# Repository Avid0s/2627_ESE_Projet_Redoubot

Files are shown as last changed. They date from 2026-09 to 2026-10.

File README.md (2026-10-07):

# 2627_ESE_PROJET_REDOUBOT

[Diagramme draw.io](https://app.diagrams.net/#G1vOe_3MKJzJUBpPdtP-GZ-P4Yg8ShrS2W#%7B%22pageId%22%3A%22ODYEVYFFD_o6EEWGu_Kz%22%7D)

[PDF MPU 6050](https://docs.google.com/document/d/1O3AgjvM2_tZX7ABNkbS3lNtyRqeFLNvJ6qVK9URJxNs/edit?usp=drive_link)

| Composant | Référence | Lien | Quantité |
|---|---|---|---|
| STM32 | CPU_DS_stm32g431rb | [Datasheet](https://github.com/Avid0s/2627_ESE_Projet_Redoubot/blob/main/Datasheet/CPU_DS_stm32g431rb.pdf) | x1 |
| Drivers moteur | DRV8833 | [Datasheet](https://github.com/Avid0s/2627_ESE_Projet_Redoubot/blob/main/Datasheet/Drivers_drv8833.pdf) | x1 |
| Moteurs | FIT0483 | [Datasheet](https://github.com/Avid0s/2627_ESE_Projet_Redoubot/blob/main/Datasheet/Datasheet_moteur_FIT0483.pdf) | x2|
| Gyroscope/accelerometre | MPU6050 | [Datasheet](https://github.com/Avid0s/2627_ESE_Projet_Redoubot/blob/main/Datasheet/Gyro_MPU-6000_DATASHEET.pdf) | x1 |
| Servomotor | SER0039 | [Datasheet](https://github.com/Avid0s/2627_ESE_Projet_Redoubot/blob/main/Datasheet/Servo_SER0039.pdf) | x2 |
| TOF sensor | VL53LL0X | [Datasheet](https://github.com/Avid0s/2627_ESE_Projet_Redoubot/blob/main/Datasheet/TOF_vl53l0x.pdf) [Breakout Board](https://github.com/lfiack/ENSEA_VL53L0CXV0DH-1)| x1 |
| Capteur de couleur | Adafruit APDS9960 | [Datasheet](https://github.com/Avid0s/2627_ESE_Projet_Redoubot/blob/main/Datasheet/Capteur_Couleur_9075d4adc221e10b04bda232a5ca3905.pdf) | x1 |
| BMS | BQ25896RTWR | [Datasheet](https://github.com/Avid0s/2627_ESE_Projet_Redoubot/blob/main/Datasheet/BMS_bq25896.pdf) | x1 |  
| Batterie Lithium | XX | Fournie par ENSEA | x1 |
| Fuel Gauge | BQ27220YZFR | [Datasheet](https://www.ti.com/lit/ds/symlink/bq27220.pdf?ts=1790240333206&ref_url=https%253A%252F%252Fwww.mouser.fr%252F) | x1 |
| Sonde de programation | Conn_ST_STDC14 | Fournie par ENSEA| x1 |

La facon dont l'implémentation de fonctionnalités sera faite sera la suivante:

1 branche = 1 fonctionnalitée

Les branches seront nommées JMA/nom_de_la_fonctionnalitée pour une branche fonctionnalité de J. Mansard par exemple

Aucun push ne sera fait directement sur le main, tout sera merge post peer review

Cette methodologie vise à éviter les merge conflicts et simplifier l'assemblage des différents modules

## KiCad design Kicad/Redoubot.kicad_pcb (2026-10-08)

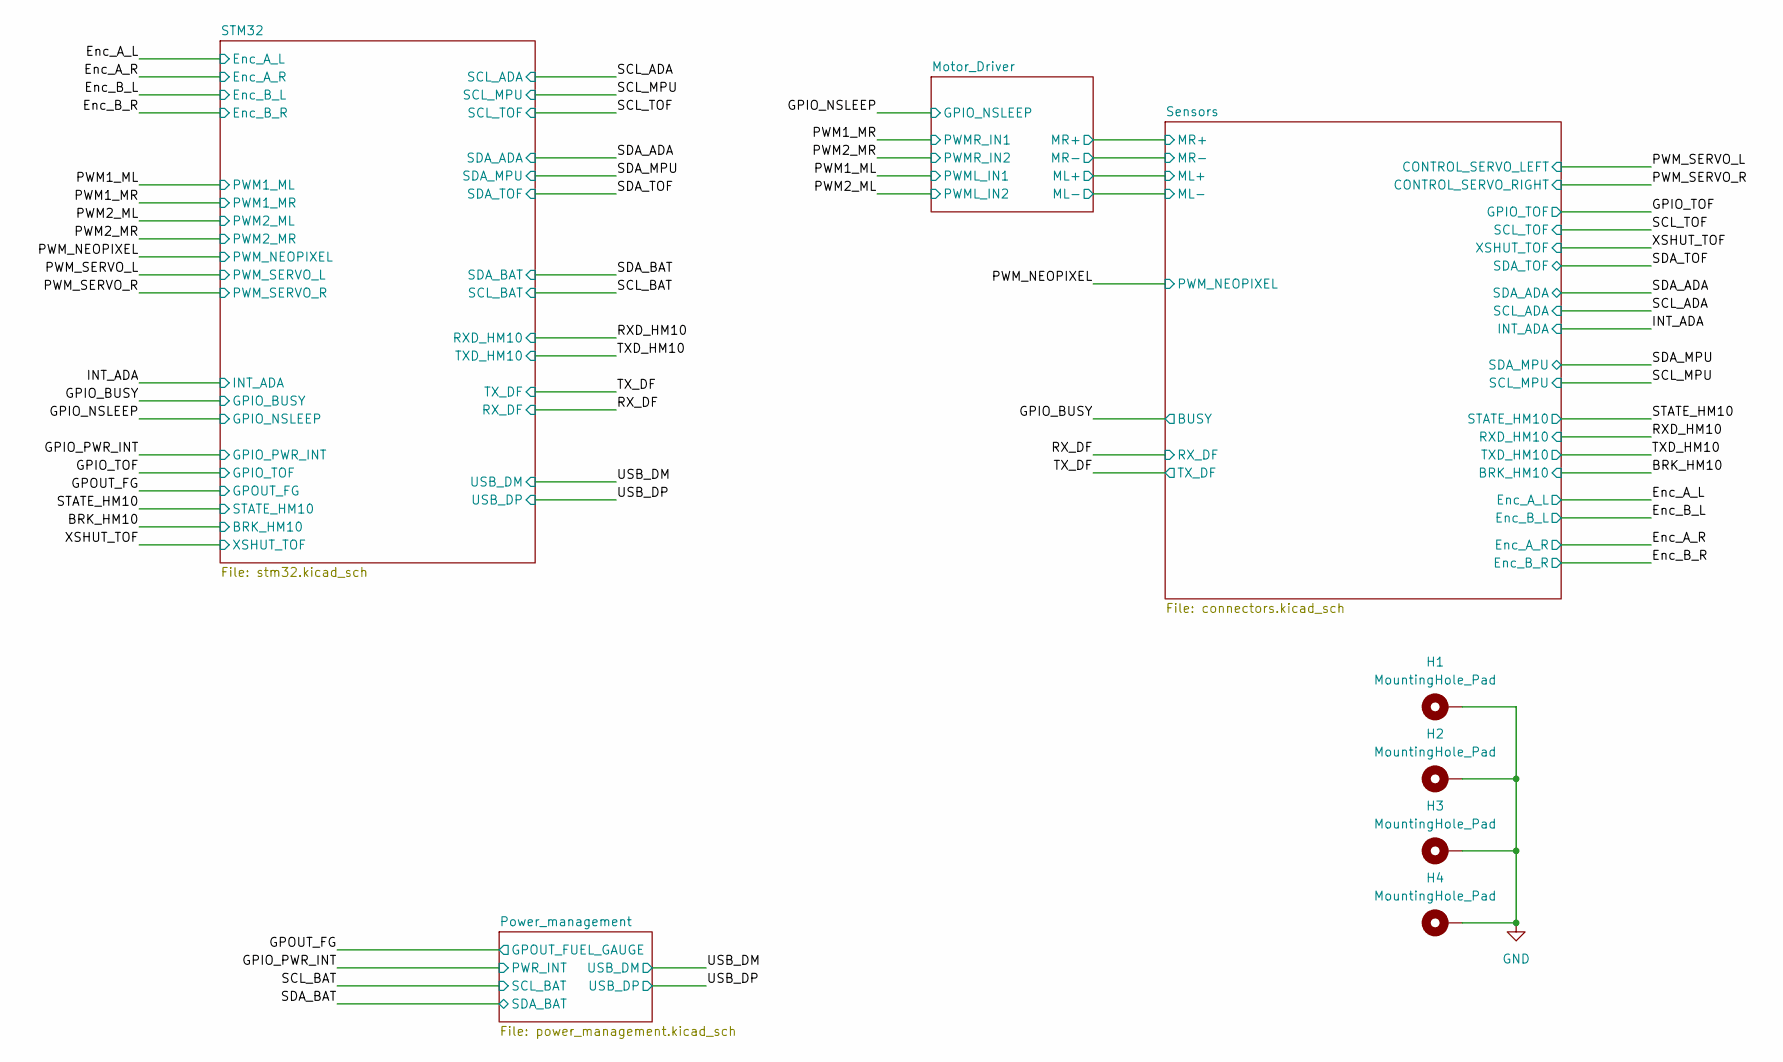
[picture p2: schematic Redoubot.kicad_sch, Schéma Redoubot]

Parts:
H1, H2, H3, H4: MountingHole_Pad; MountingHole_3.2mm_M3_ISO7380_Pad_TopBottom

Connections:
GND: H1.1 (1_1), H2.1 (1_1), H3.1 (1_1), H4.1 (1_1); also elsewhere on the board

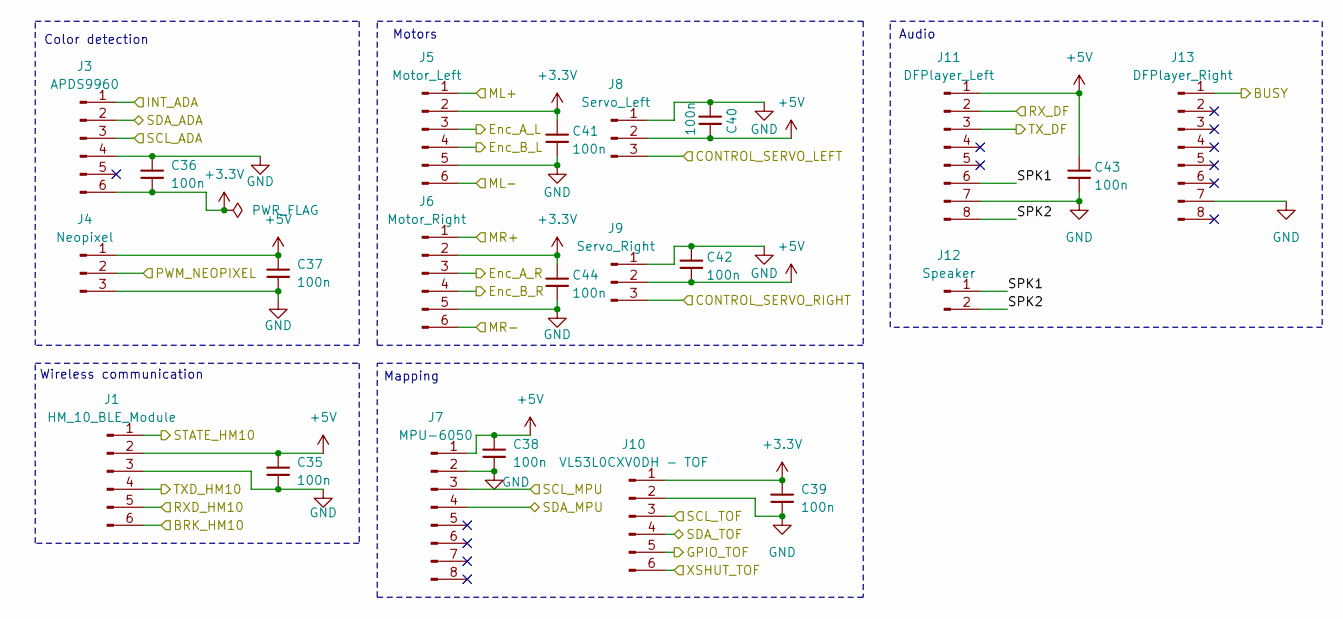
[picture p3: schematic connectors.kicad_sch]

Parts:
C35, C36, C37, C38, C39, C40, C41, C42, C43, C44: 100n; C_0402_1005Metric; JLCPCB Part # C1525
J1: HM_10_BLE_Module; JST_XH_B6B-XH-A_1x06_P2.50mm_Vertical
J3: APDS9960; JST_XH_B6B-XH-A_1x06_P2.50mm_Vertical
J4: Neopixel; JST_XH_B3B-XH-A_1x03_P2.50mm_Vertical
J5: Motor_Left; JST_XH_B6B-XH-A_1x06_P2.50mm_Vertical
J6: Motor_Right; JST_XH_B6B-XH-A_1x06_P2.50mm_Vertical
J7: MPU-6050; PinSocket_1x08_P2.54mm_Vertical; LCSC C24112
J8: Servo_Left; JST_XH_B3B-XH-A_1x03_P2.50mm_Vertical
J9: Servo_Right; JST_XH_B3B-XH-A_1x03_P2.50mm_Vertical
J10: VL53L0CXV0DH - TOF; JST_XH_B6B-XH-A_1x06_P2.50mm_Vertical; LCSC C91199
J11: DFPlayer_Left; PinSocket_1x08_P2.54mm_Vertical
J12: Speaker; JST_XH_B2B-XH-A_1x02_P2.50mm_Vertical
J13: DFPlayer_Right; PinSocket_1x08_P2.54mm_Vertical

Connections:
+3.3V: C36.2, C39.1, C41.1, C44.1, J3.6, J5.2, J6.2, J10.1; also elsewhere on the board
+5V: C35.1, C37.1, C38.1, C40.2, C42.2, C43.1, J1.2, J4.1, J7.1, J8.2, J9.2, J11.1; also elsewhere on the board
/BRK_HM10: J1.6; also elsewhere on the board
/Enc_A_L: J5.3; also elsewhere on the board
/Enc_A_R: J6.3; also elsewhere on the board
/Enc_B_L: J5.4; also elsewhere on the board
/Enc_B_R: J6.4; also elsewhere on the board
/GPIO_BUSY: J13.1; also elsewhere on the board
/GPIO_TOF: J10.5; also elsewhere on the board
/INT_ADA: J3.1; also elsewhere on the board
/Motor_Driver/ML+: J5.1; also elsewhere on the board
/Motor_Driver/ML-: J5.6; also elsewhere on the board
/Motor_Driver/MR+: J6.1; also elsewhere on the board
/Motor_Driver/MR-: J6.6; also elsewhere on the board
/PWM_NEOPIXEL: J4.2; also elsewhere on the board
/PWM_SERVO_L: J8.3; also elsewhere on the board
/PWM_SERVO_R: J9.3; also elsewhere on the board
/RXD_HM10: J1.5; also elsewhere on the board
/RX_DF: J11.2; also elsewhere on the board
/SCL_ADA: J3.3, J7.3, J10.3; also elsewhere on the board
/SDA_ADA: J3.2, J7.4, J10.4; also elsewhere on the board
/STATE_HM10: J1.1; also elsewhere on the board
/Sensors/SPK1: J11.6, J12.1
/Sensors/SPK2: J11.8, J12.2
/TXD_HM10: J1.4; also elsewhere on the board
/TX_DF: J11.3; also elsewhere on the board
/XSHUT_TOF: J10.6; also elsewhere on the board
GND: C35.2, C36.1, C37.2, C38.2, C39.2, C40.1, C41.2, C42.1, C43.2, C44.2, J1.3, J3.4, J4.3, J5.5, J6.5, J7.2, J8.1, J9.1, J10.2, J11.7, J13.7; also elsewhere on the board

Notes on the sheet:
Motors
Wireless communication
Color detection
Mapping
Audio

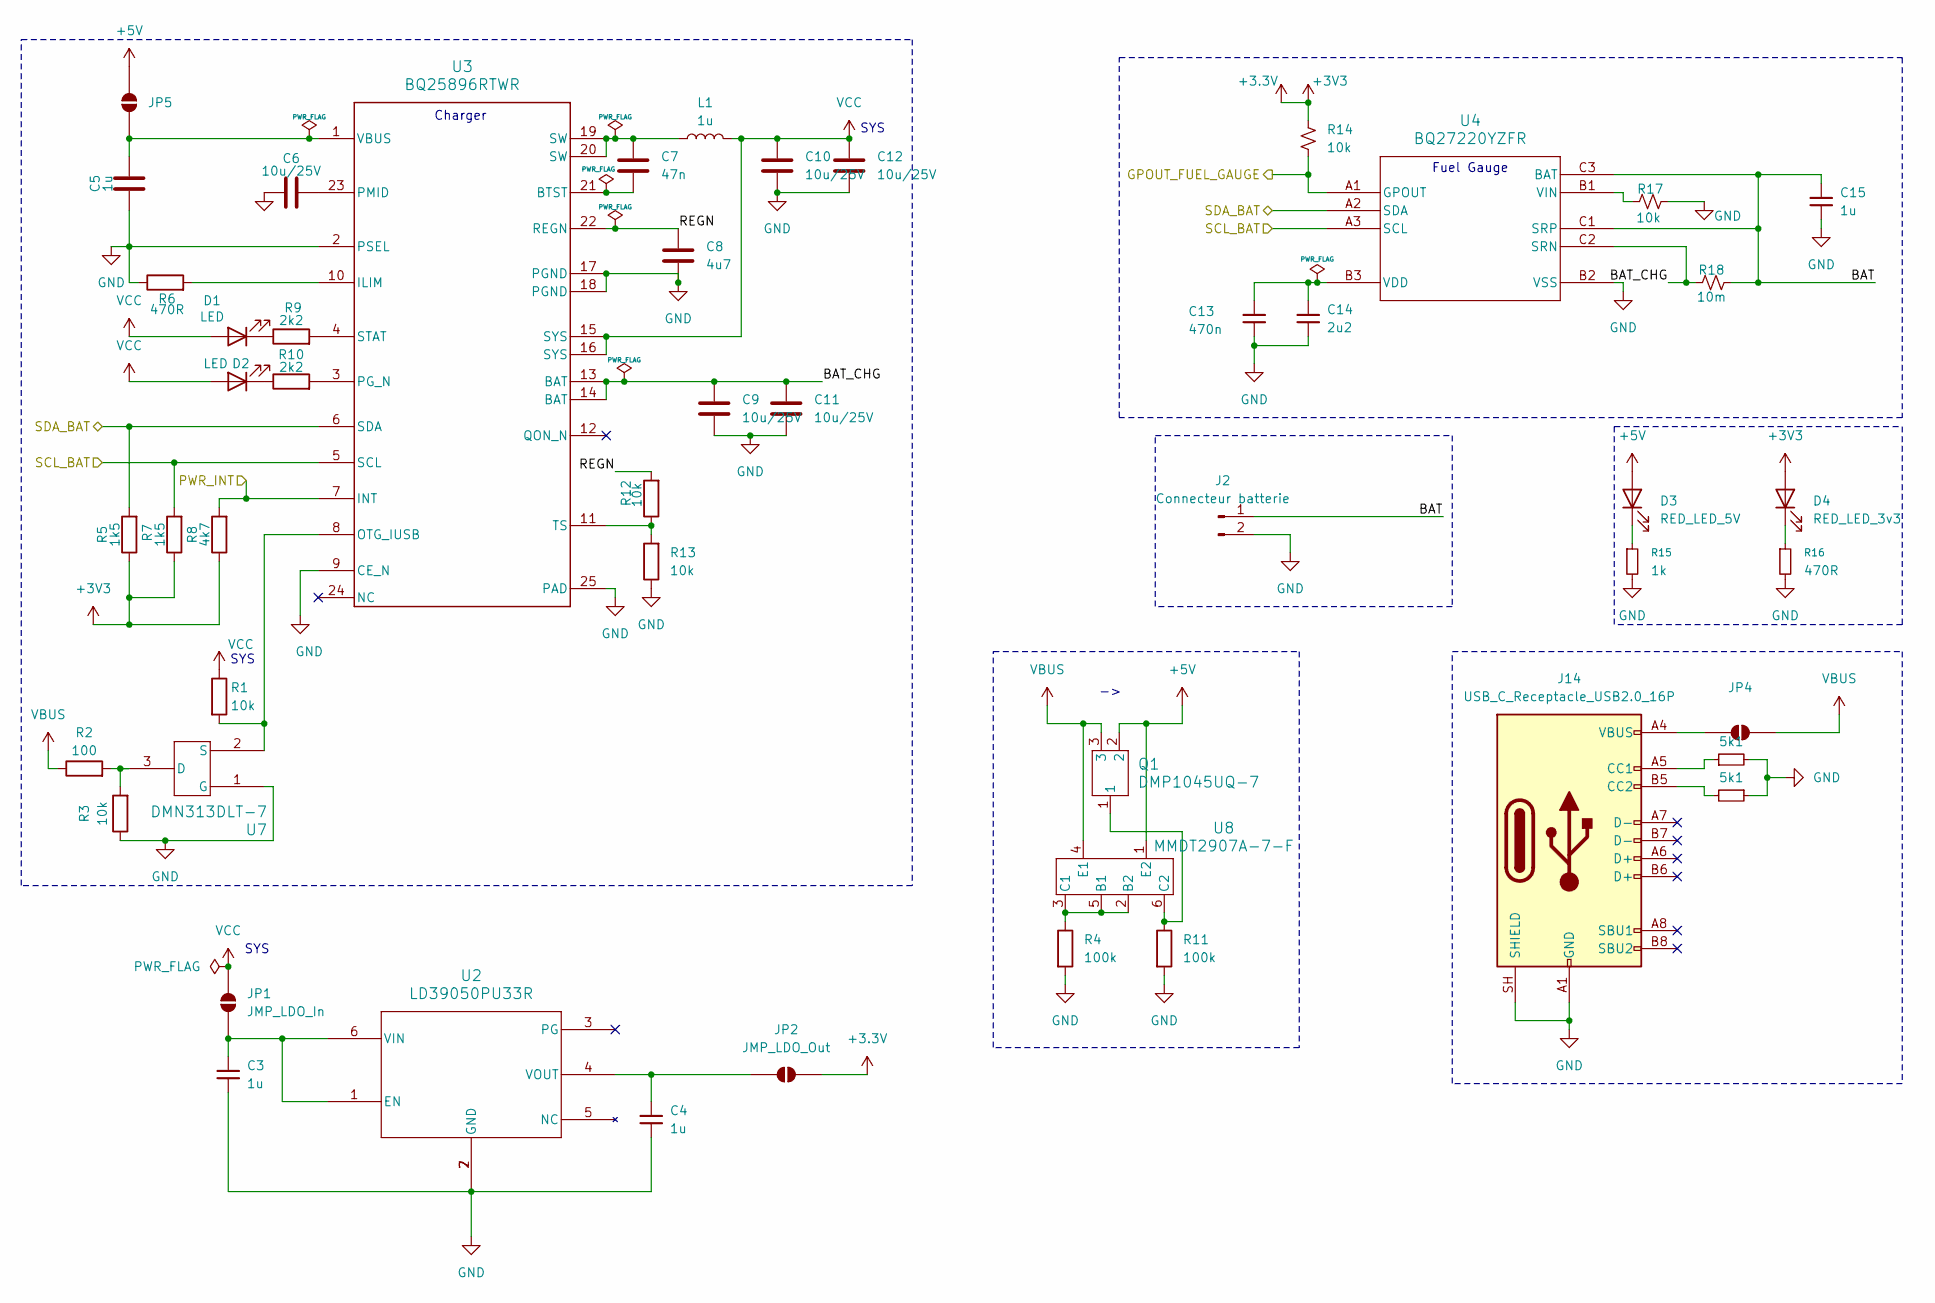
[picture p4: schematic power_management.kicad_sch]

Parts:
C3, C4, C5, C15: 1u; C_0402_1005Metric; JLCPCB Part # C52923
C6, C9, C10, C11, C12: 10u/25V; C_0603_1608Metric; JLCPCB Part # C96446
C7: 47n; C_0603_1608Metric; JLCPCB Part # C1622
C8: 4u7; C_0402_1005Metric; JLCPCB Part # C23733
C13: 470n; C_0603_1608Metric; JLCPCB Part # C1623
C14: 2u2; C_0402_1005Metric; JLCPCB Part # C12530
D1, D2: LED; LED_0603_1608Metric; JLCPCB Part # C965804
D3: RED_LED_5V; LED_0603_1608Metric; JLCPCB Part # C965804
D4: RED_LED_3v3; LED_0603_1608Metric; JLCPCB Part # C965804
J2: Connecteur batterie; JST_XH_B2B-XH-A_1x02_P2.50mm_Vertical
J14: USB_C_Receptacle_USB2.0_16P; USB_C_Receptacle_GCT_USB4105-xx-A_16P_TopMnt_Horizontal
JP1: JMP_LDO_In; SolderJumper-2_P1.3mm_Open_TrianglePad1.0x1.5mm
JP2: JMP_LDO_Out; SolderJumper-2_P1.3mm_Open_TrianglePad1.0x1.5mm
JP4, JP5: JMP_Battery; SolderJumper-2_P1.3mm_Open_TrianglePad1.0x1.5mm
L1: 1u; L_Sunlord_SWPA4030S; JLCPCB Part # C42193
Q1: DMP1045UQ-7; DMP1045UQ-7_DIO; JLCPCB Part # C706746
R1, R3, R12, R13, R14, R17: 10k; R_0402_1005Metric; JLCPCB Part # C25744
R2: 100; R_0402_1005Metric; JLCPCB Part # C25076
R4, R11: 100k; R_0402_1005Metric; JLCPCB Part # C25741
R5, R7: 1k5; R_0402_1005Metric; JLCPCB Part # C25867
R6, R16: 470R; R_0402_1005Metric; JLCPCB Part # C25117
R8: 4k7; R_0402_1005Metric; JLCPCB Part # C25900
R9, R10: 2k2; R_0402_1005Metric; JLCPCB Part # C25879
R15: 1k; R_0402_1005Metric; JLCPCB Part # C11702
R18: 10m; R_1206_3216Metric; JLCPCB Part # C105362
R20, R21: 5k1; R_0402_1005Metric; JLCPCB Part # C25905
U2: LD39050PU33R; DFN6_3X3_STM; JLCPCB Part # C132827
U3: BQ25896RTWR; RTW0024H; LCSC C181475
U4: BQ27220YZFR; BGA-9_1.6x1.6mm_Layout3x3_P0.5mm; LCSC C528617
U7: DMN313DLT-7; SOT-523_DIO; JLCPCB Part # C155524
U8: MMDT2907A-7-F; SOT-363_DIO; JLCPCB Part # C460232

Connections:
+3.3V: D4.2 (A), JP2.2 (B), R5.1, R7.1, R8.1, R14.1; also elsewhere on the board
+5V: D3.2 (A), JP5.2 (B), Q1.2, U8.1 (E2); also elsewhere on the board
/GPIO_PWR_INT: R8.2, U3.7 (INT); also elsewhere on the board
/GPOUT_FG: R14.2, U4.A1 (GPOUT); also elsewhere on the board
/Power_management/BAT: C15.1, J2.1, R18.2, U4.C1 (SRP), U4.C3 (BAT)
/Power_management/BAT_CHG: C9.2, C11.2, R18.1, U3.13 (BAT), U3.14 (BAT), U4.C2 (SRN)
/Power_management/REGN: C8.2, R12.2, U3.22 (REGN)
/SCL_BAT: R7.2, U3.5 (SCL), U4.A3 (SCL); also elsewhere on the board
/SDA_BAT: R5.2, U3.6 (SDA), U4.A2 (SDA); also elsewhere on the board
GND: C3.1, C4.2, C5.1, C6.1, C8.1, C9.1, C10.1, C11.1, C12.1, C13.2, C14.2, C15.2, J2.2, J14.A1 (GND), J14.A12 (GND), J14.B1 (GND), J14.B12 (GND), J14.SH (SHIELD), R3.1, R4.2, R6.1, R11.2, R13.1, R15.2, R16.2, R17.1, R20.2, R21.1, U2.2 (GND), U2.7 (GND), U3.2 (PSEL), U3.9 (CE_N), U3.17 (PGND), U3.18 (PGND), U3.25 (PAD), U4.B2 (VSS), U7.1 (G); also elsewhere on the board
unnamed: C7.2, L1.1, U3.19 (SW), U3.20 (SW)
unnamed: D1.1 (K), R9.1
unnamed: D2.1 (K), R10.1
unnamed: D3.1 (K), R15.1
unnamed: D4.1 (K), R16.1
unnamed: J14.A5 (CC1), R20.1
unnamed: J14.B5 (CC2), R21.2
unnamed: C3.2, JP1.1 (A), U2.1 (EN), U2.6 (VIN)
unnamed: C4.1, JP2.1 (A), U2.4 (VOUT)
unnamed: J14.A4 (VBUS), J14.A9 (VBUS), J14.B4 (VBUS), J14.B9 (VBUS), JP4.1 (A)
unnamed: C5.2, JP5.1 (A), U3.1 (VBUS)
unnamed: C7.1, U3.21 (BTST)
unnamed: R6.2, U3.10 (ILIM)
unnamed: R1.2, U3.8 (OTG_IUSB), U7.2 (S)
unnamed: R10.2, U3.3 (PG_N)
unnamed: C6.2, U3.23 (PMID)
unnamed: R9.2, U3.4 (STAT)
unnamed: R12.1, R13.2, U3.11 (TS)
unnamed: C13.1, C14.1, U4.B3 (VDD)
unnamed: R17.2, U4.B1 (VIN)
unnamed: R2.2, R3.2, U7.3 (D)
unnamed: R4.1, U8.2 (B2), U8.3 (C1), U8.5 (B1)
unnamed: Q1.1, R11.1, U8.6 (C2)
VBUS: JP4.2 (B), Q1.3, R2.1, U8.4 (E1)
VCC: C10.2, C12.2, D1.2 (A), D2.2 (A), JP1.2 (B), L1.2, R1.1, U3.15 (SYS), U3.16 (SYS)

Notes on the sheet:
SYS
Fuel Gauge
Charger

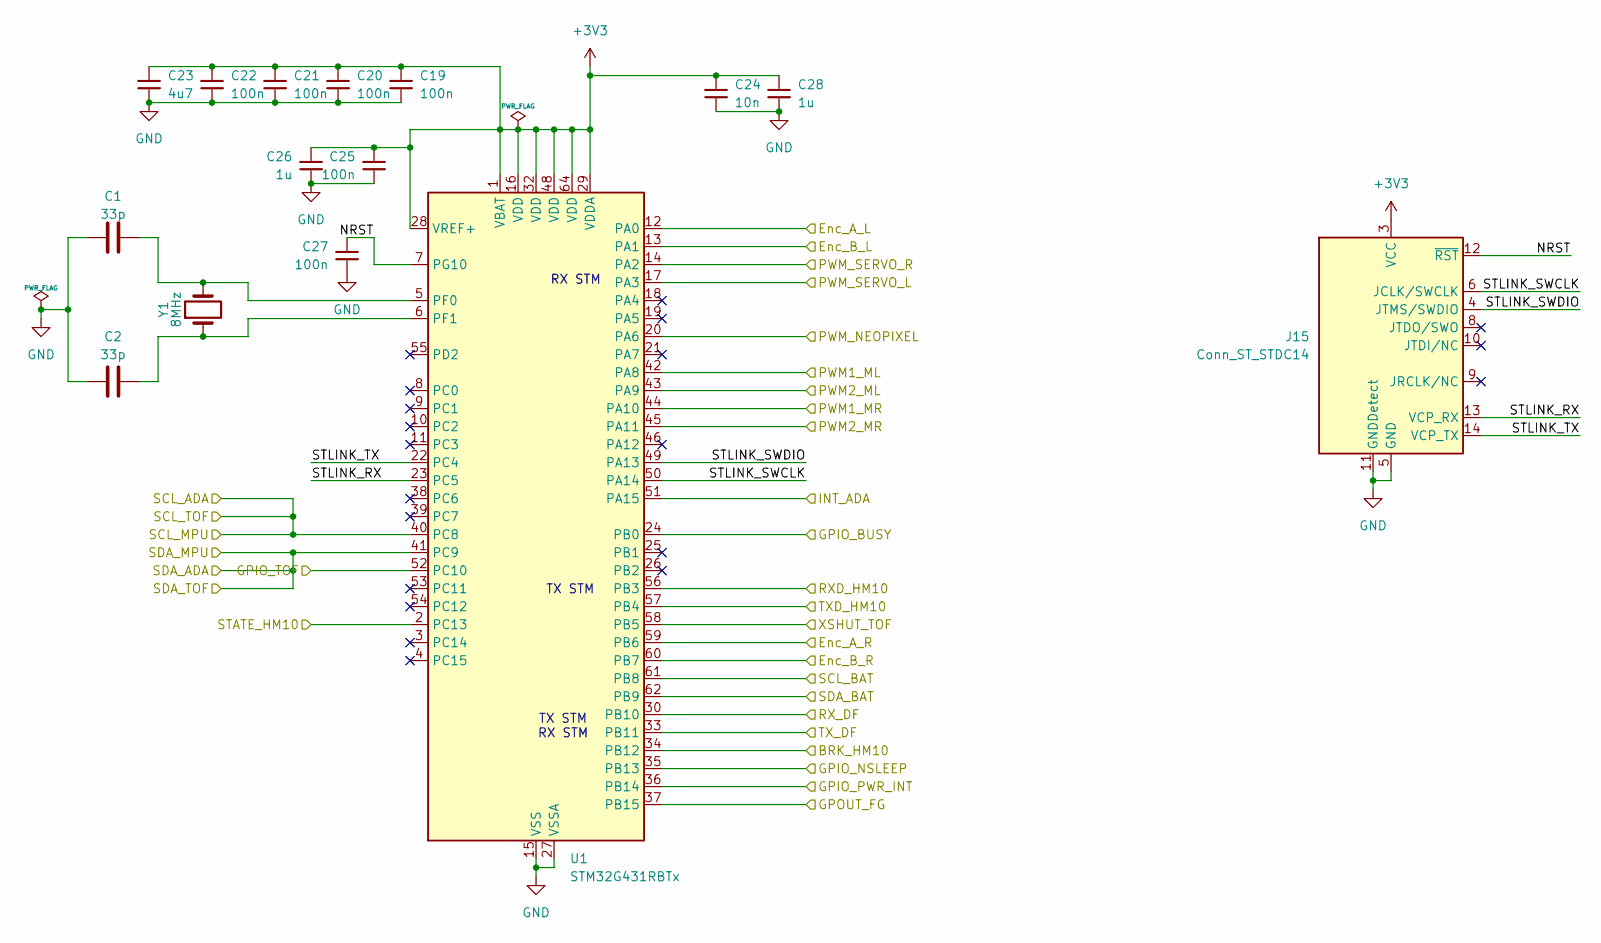
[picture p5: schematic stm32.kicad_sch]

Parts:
C1, C2: 33p; C_0402_1005Metric; JLCPCB Part # C1562
C19, C20, C21, C22, C25, C27: 100n; C_0402_1005Metric; JLCPCB Part # C1525
C23: 4u7; C_0402_1005Metric; JLCPCB Part # C23733
C24: 10n; C_0402_1005Metric; JLCPCB Part # C15195
C26, C28: 1u; C_0402_1005Metric; JLCPCB Part # C52923
J15: Conn_ST_STDC14; PinHeader_2x07_P1.27mm_Vertical_SMD
U1: STM32G431RBTx; LQFP-64_10x10mm_P0.5mm; LCSC C431633
Y1: 8MHz; Crystal_SMD_HC49-SD; JLCPCB Part # C115962

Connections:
+3.3V: C19.1, C20.1, C21.1, C22.1, C23.1, C24.1, C25.1, C26.1, C28.1, J15.3 (VCC), U1.1 (VBAT), U1.16 (VDD), U1.28 (VREF+), U1.29 (VDDA), U1.32 (VDD), U1.48 (VDD), U1.64 (VDD); also elsewhere on the board
/BRK_HM10: U1.34 (PB12); also elsewhere on the board
/Enc_A_L: U1.12 (PA0); also elsewhere on the board
/Enc_A_R: U1.59 (PB6); also elsewhere on the board
/Enc_B_L: U1.13 (PA1); also elsewhere on the board
/Enc_B_R: U1.60 (PB7); also elsewhere on the board
/GPIO_BUSY: U1.24 (PB0); also elsewhere on the board
/GPIO_NSLEEP: U1.35 (PB13); also elsewhere on the board
/GPIO_PWR_INT: U1.36 (PB14); also elsewhere on the board
/GPIO_TOF: U1.52 (PC10); also elsewhere on the board
/GPOUT_FG: U1.37 (PB15); also elsewhere on the board
/INT_ADA: U1.51 (PA15); also elsewhere on the board
/PWM1_ML: U1.42 (PA8); also elsewhere on the board
/PWM1_MR: U1.44 (PA10); also elsewhere on the board
/PWM2_ML: U1.43 (PA9); also elsewhere on the board
/PWM2_MR: U1.45 (PA11); also elsewhere on the board
/PWM_NEOPIXEL: U1.20 (PA6); also elsewhere on the board
/PWM_SERVO_L: U1.17 (PA3); also elsewhere on the board
/PWM_SERVO_R: U1.14 (PA2); also elsewhere on the board
/RXD_HM10: U1.56 (PB3); also elsewhere on the board
/RX_DF: U1.30 (PB10); also elsewhere on the board
/SCL_ADA: U1.40 (PC8); also elsewhere on the board
/SCL_BAT: U1.61 (PB8); also elsewhere on the board
/SDA_ADA: U1.41 (PC9); also elsewhere on the board
/SDA_BAT: U1.62 (PB9); also elsewhere on the board
/STATE_HM10: U1.2 (PC13); also elsewhere on the board
/STM32/NRST: C27.1, J15.12 (~RST), U1.7 (PG10)
/STM32/STLINK_RX: J15.13 (VCP_RX), U1.23 (PC5)
/STM32/STLINK_SWCLK: J15.6 (JCLK/SWCLK), U1.50 (PA14)
/STM32/STLINK_SWDIO: J15.4 (JTMS/SWDIO), U1.49 (PA13)
/STM32/STLINK_TX: J15.14 (VCP_TX), U1.22 (PC4)
/TXD_HM10: U1.57 (PB4); also elsewhere on the board
/TX_DF: U1.33 (PB11); also elsewhere on the board
/XSHUT_TOF: U1.58 (PB5); also elsewhere on the board
GND: C1.1, C2.1, C19.2, C20.2, C21.2, C22.2, C23.2, C24.2, C25.2, C26.2, C27.2, C28.2, J15.5 (GND), J15.7 (GND), J15.11 (GNDDetect), U1.15 (VSS), U1.27 (VSSA), U1.31 (VSS), U1.47 (VSS), U1.63 (VSS); also elsewhere on the board
unnamed: C1.2, U1.5 (PF0), Y1.2
unnamed: C2.2, U1.6 (PF1), Y1.1

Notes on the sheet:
RX STM
TX STM RX STM
TX STM

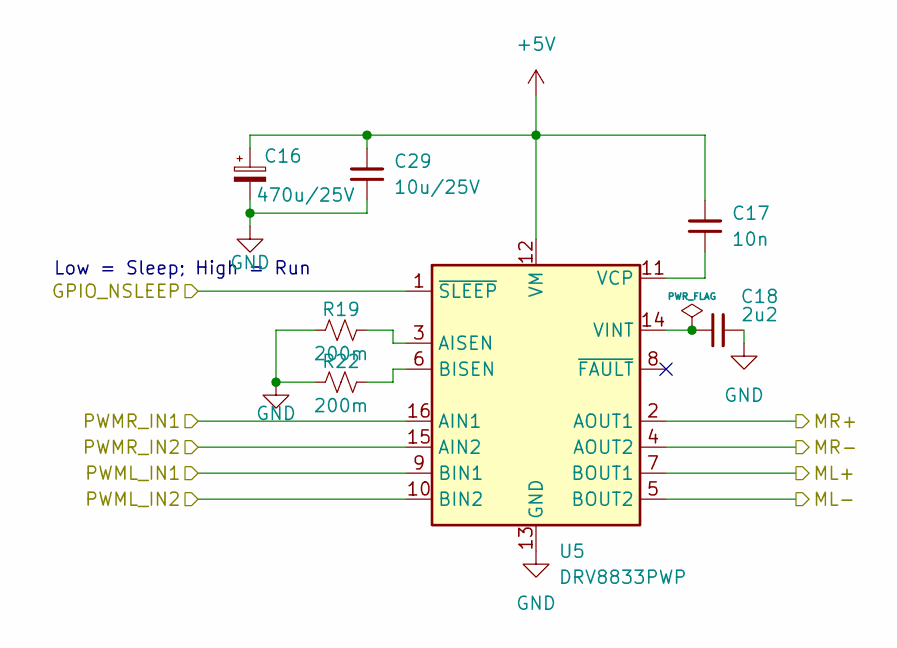
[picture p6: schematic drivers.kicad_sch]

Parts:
C16: 470u/25V; CP_Elec_8x10.5; JLCPCB Part # C48935394
C17: 10n; C_0402_1005Metric; JLCPCB Part # C15195
C18: 2u2; C_0402_1005Metric; JLCPCB Part # C12530
C29: 10u/25V; C_0603_1608Metric; JLCPCB Part # C96446
R19, R22: 200m; R_1206_3216Metric; JLCPCB Part # C160920
U5: DRV8833PWP; HTSSOP-16-1EP_4.4x5mm_P0.65mm_EP3.4x5mm_Mask2.46x2.31mm_The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; LCSC C50506

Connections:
+5V: C16.1, C17.1, C29.1, U5.12 (VM); also elsewhere on the board
/GPIO_NSLEEP: U5.1 (~SLEEP); also elsewhere on the board
/Motor_Driver/ML+: U5.7 (BOUT1); also elsewhere on the board
/Motor_Driver/ML-: U5.5 (BOUT2); also elsewhere on the board
/Motor_Driver/MR+: U5.2 (AOUT1); also elsewhere on the board
/Motor_Driver/MR-: U5.4 (AOUT2); also elsewhere on the board
/PWM1_ML: U5.9 (BIN1); also elsewhere on the board
/PWM1_MR: U5.16 (AIN1); also elsewhere on the board
/PWM2_ML: U5.10 (BIN2); also elsewhere on the board
/PWM2_MR: U5.15 (AIN2); also elsewhere on the board
GND: C16.2, C18.2, C29.2, R19.1, R22.1, U5.13 (GND), U5.17 (GND); also elsewhere on the board
unnamed: R19.2, U5.3 (AISEN)
unnamed: R22.2, U5.6 (BISEN)
unnamed: C17.2, U5.11 (VCP)
unnamed: C18.1, U5.14 (VINT)

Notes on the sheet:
Low = Sleep; High = Run

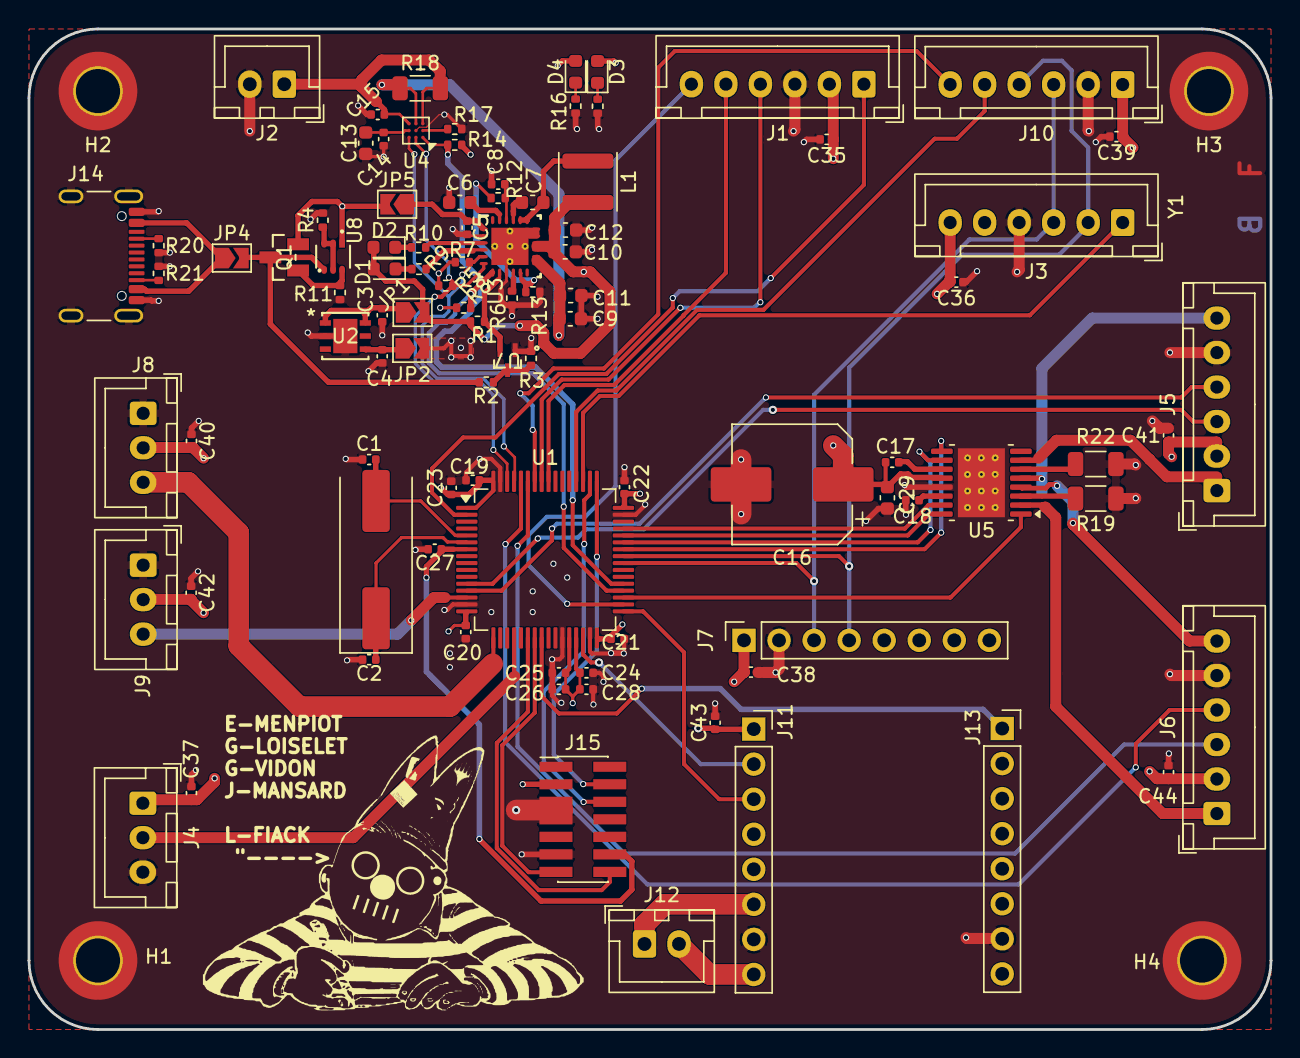
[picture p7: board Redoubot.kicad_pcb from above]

Board: 4 copper layers, 90.0 x 72.5 mm, 98 parts (0 on the bottom side), 76 nets.

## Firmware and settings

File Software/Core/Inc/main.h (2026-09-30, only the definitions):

#define Quartz_0_Pin GPIO_PIN_0
#define Quartz_0_GPIO_Port GPIOF
#define Quartz_1_Pin GPIO_PIN_1
#define Quartz_1_GPIO_Port GPIOF
#define PWM1_ML_Pin GPIO_PIN_0
#define PWM1_ML_GPIO_Port GPIOC
#define PWM2_ML_Pin GPIO_PIN_1
#define PWM2_ML_GPIO_Port GPIOC
#define PWM1_MR_Pin GPIO_PIN_2
#define PWM1_MR_GPIO_Port GPIOC
#define PWM2_MR_Pin GPIO_PIN_3
#define PWM2_MR_GPIO_Port GPIOC
#define Enc_B_R_Pin GPIO_PIN_0
#define Enc_B_R_GPIO_Port GPIOA
#define Enc_B_L_Pin GPIO_PIN_1
#define Enc_B_L_GPIO_Port GPIOA
#define Enc_A_L_Pin GPIO_PIN_2
#define Enc_A_L_GPIO_Port GPIOA
#define TXD_HM10_Pin GPIO_PIN_3
#define TXD_HM10_GPIO_Port GPIOA
#define PWM_NEOPIXEL_Pin GPIO_PIN_6
#define PWM_NEOPIXEL_GPIO_Port GPIOA
#define GPIO_BUSY_Pin GPIO_PIN_0
#define GPIO_BUSY_GPIO_Port GPIOB
#define RX_DF_Pin GPIO_PIN_10
#define RX_DF_GPIO_Port GPIOB
#define TX_DF_Pin GPIO_PIN_11
#define TX_DF_GPIO_Port GPIOB
#define BRK_HM10_Pin GPIO_PIN_12
#define BRK_HM10_GPIO_Port GPIOB
#define GPIO_NSLEEP_Pin GPIO_PIN_13
#define GPIO_NSLEEP_GPIO_Port GPIOB
#define GPIO_PWR_INT_Pin GPIO_PIN_14
#define GPIO_PWR_INT_GPIO_Port GPIOB
#define GPOUT_FG_Pin GPIO_PIN_15
#define GPOUT_FG_GPIO_Port GPIOB
#define SCL_MPU_Pin GPIO_PIN_8
#define SCL_MPU_GPIO_Port GPIOC
#define SDA_MPU_Pin GPIO_PIN_9
#define SDA_MPU_GPIO_Port GPIOC
#define INT_ADA_Pin GPIO_PIN_9
#define INT_ADA_GPIO_Port GPIOA
#define Enc_A_R_Pin GPIO_PIN_10
#define Enc_A_R_GPIO_Port GPIOA
#define RXD_HM10_Pin GPIO_PIN_3
#define RXD_HM10_GPIO_Port GPIOB
#define GPIO_OTG_EN_Pin GPIO_PIN_4
#define GPIO_OTG_EN_GPIO_Port GPIOB
#define XSHUT_TOF_Pin GPIO_PIN_5
#define XSHUT_TOF_GPIO_Port GPIOB
#define GPIO_TOF_Pin GPIO_PIN_6
#define GPIO_TOF_GPIO_Port GPIOB
#define PWM_SERVO_R_Pin GPIO_PIN_7
#define PWM_SERVO_R_GPIO_Port GPIOB
#define PWM_SERVO_L_Pin GPIO_PIN_8
#define PWM_SERVO_L_GPIO_Port GPIOB
#define STATE_HM10_Pin GPIO_PIN_9
#define STATE_HM10_GPIO_Port GPIOB

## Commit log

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2026-09-17 Fix formatting of TOF sensor entry in README
2026-09-17 Modify TOF sensor quantity in README
    Updated the quantity of VL53LL0X TOF sensors from x2 to x1.
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2026-09-24 unzipped kicad document
    [Redoubot.kicad_pcb, Redoubot.kicad_sch]
2026-09-24 chore: unzipped kicad file
    [Redoubot.kicad_pcb, Redoubot.kicad_sch]
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2026-09-24 added the crystal and some missing connections
    [Redoubot.kicad_sch]
2026-09-24 connected the crystal to the STM32
    [Redoubot.kicad_sch]
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2026-09-24 Added numerical values of the crystal and the associated capacitors
    [Redoubot.kicad_sch]
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2026-09-24 Added datasheer for fuel gauge and corrected name for BMS
2026-09-28 chore: add .ioc v0.1; removed nested kicad files; fixed kicad libraries not registering
    [Redoubot.kicad_pcb, Redoubot.kicad_sch, connectors.kicad_sch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]
2026-09-28 chore: renaming of hierchical sheet power to power_management to better match the use, creation of drivers and sensors HS to have clear sheets
    [Redoubot.kicad_sch, connectors.kicad_sch, drivers.kicad_sch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]
2026-09-28 feat: motor driver wired in parallel mode
    [Redoubot.kicad_sch, drivers.kicad_sch]
2026-09-28 feat: added flipper zero's power management schematic for reference
2026-09-29 feat: added all remaining connectors & finished putting values on components
    [Redoubot.kicad_sch, connectors.kicad_sch, drivers.kicad_sch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]
2026-09-29 chore: wired everything possible atm, wrote down every missing links, waiting for .ioc to continue
    [Redoubot.kicad_sch, connectors.kicad_sch, power_management.kicad_sch]
2026-09-29 chore:modified gitignore to include unnecessary CubeIDE & KiCad files
2026-09-29 Ajout de l'IOC
    L'IOC ajouté est pour l'instant temporaire et devra très probablement être modifié
2026-09-29 feat: added DFPlayer Mini and HM10 connectors
    [Redoubot.kicad_sch, connectors.kicad_sch]
2026-09-29 simply added the JLCPCB Part # as an LCSC field in the component descriptions
    [Redoubot.kicad_sch, connectors.kicad_sch, drivers.kicad_sch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]
2026-09-29 Added footprints for capacitors
    [Redoubot.kicad_sch, drivers.kicad_sch, power_management.kicad_sch]
2026-09-29 Added the footprints for the resistors, inductors and the crystal
    [Redoubot.kicad_sch, drivers.kicad_sch, power_management.kicad_sch]
2026-09-29 added the footprints for the connectors
    [connectors.kicad_sch]
2026-09-29 fixed the footprint for the connector of the VL53
    [connectors.kicad_sch]
2026-09-30 feat: added usb_c charging + flashing, added +3.3V generation, added HM10 & DFMini Support, wired everything and modified ioc accordingly
    [Redoubot.kicad_sch, connectors.kicad_sch, drivers.kicad_sch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]
2026-09-30 Ajout de l'IOC
    IOC avec les pins activées et nommées suivant le Kicad
2026-09-30 chore: added jumpers, changed 5v stm input to 3v3
    [Redoubot.kicad_sch, connectors.kicad_sch, power_management.kicad_sch]
2026-09-30 replaced the footprints for resistors with 0402 variants
    [Redoubot.kicad_sch, connectors.kicad_sch, drivers.kicad_sch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]
2026-09-30 chore: added segmentation to schematic for connectors
    [Redoubot.kicad_sch, connectors.kicad_sch]
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2026-09-30 fix: Modified the footprints of the capacitors to minimise their size and replaced C2 footprint with an electrolytic capacitor
    [Redoubot.kicad_sch, connectors.kicad_sch, drivers.kicad_sch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]
2026-09-30 feat : Generated the STM32 project from the IOC file and renamed the Redoubot and CubeMX folders to Kicad and Software
    [Redoubot.kicad_pcb, Redoubot.kicad_sch, connectors.kicad_sch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]
2026-09-30 Feat: Added power LEDs 5v and 3v, Added Jumpers to battery and bms, Added segmentation in connector sheet, Added encoders, Changed page name from motor diver right to motor driver, Redid annotations,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
    [Redoubot.kicad_sch, connectors.kicad_sch, drivers.kicad_sch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]
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2026-09-30 feat: added the footprints for the solderjumpers
    [Redoubot.kicad_sch, connectors.kicad_sch, power_management.kicad_sch]
2026-09-30 feat: replaced the footprints of the connectors with fooprints of JST connectors
    [connectors.kicad_sch]
2026-09-30 fix: assigned the correct footprints to resistors R15 and R16
    [power_management.kicad_sch]
2026-09-30 feat: changed the footprints to 1206 for the shunt resistors R18 and R19 and put a JST connector footprint for the Bluetooth Module
    [connectors.kicad_sch, drivers.kicad_sch, power_management.kicad_sch]
2026-09-30 fix: replaced the fooprints of the connectors of the TOF and Bluetooth Module with vertical ones
    [connectors.kicad_sch]
2026-09-30 feat: added power flags, no errors during ERC
    [Redoubot.kicad_sch, drivers.kicad_sch, power_management.kicad_sch]
2026-10-05 feat: electrical schematic validated
    [Redoubot.kicad_sch, connectors.kicad_sch, drivers.kicad_sch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]
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2026-10-05 feat : updated timers, prescalers and clocks for pwm, i2c and cpu clock
2026-10-05 feat: added the footprints for new components and started assigning the JLCPCB part numbers
    [connectors.kicad_sch, drivers.kicad_sch, power_management.kicad_sch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]
2026-10-05 Feat: Placed components on wiring schematic, chore: fixed footprint names and values
    [Redoubot.kicad_pcb, Redoubot.kicad_sch, connectors.kicad_sch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]
2026-10-05 feat: started routing, notably connecting the GNDs
    [Redoubot.kicad_pcb]
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2026-10-07 chore: redid placement from the ground up
    [Redoubot.kicad_pcb, Redoubot.kicad_sch, connectors.kicad_sch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]
2026-10-07 chore: added programming probe to diagram and readme
    Added programming probe information to the README.
2026-10-07 feat: placed the power block and started routing
    [Redoubot.kicad_pcb, Redoubot.kicad_sch, connectors.kicad_sch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]
2026-10-07 feat: added the ground plane
    [Redoubot.kicad_pcb]
2026-10-07 feat: continued with the routing
    [Redoubot.kicad_pcb]
2026-10-07 feat: added routing for most of the connectors
    [Redoubot.kicad_pcb]
2026-10-07 chore: modified some routes to reduce the space taken on the other side of the board
    [Redoubot.kicad_pcb]
2026-10-07 Feet: finished wiring pcb
    53 errors are normal and can be ignored, but should be fixed. PCB can be shrunk by a decent amount.
    [Redoubot.kicad_pcb, stm32.kicad_sch]
2026-10-08 Chore: Changements M. Fiack
    [Redoubot.kicad_pcb, Redoubot.kicad_sch, connectors.kicad_sch]
2026-10-08 chore: finished adding all the JLCPCB part numbers for all the components
    [drivers.kicad_sch, power_management.kicad_sch, stm32.kicad_sch]
2026-10-08 Feat : Finished wiring pcb
    shrunk pcb and fixed issues
    [Redoubot.kicad_pcb, power_management.kicad_sch]
2026-10-08 Feat: added silkscreen and logo
    [Redoubot.kicad_pcb]
2026-10-12 chore: silkscreen fix
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2026-10-16 chore: modified the csv and bom files to remove connectors, add the JLCPCB part id for the USB receptacle and recentre the fuel gauge
2026-10-19 chore : Update TODO list in README.md
    Added tasks for module list and software flowchart.
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2026-11-05 Feat : added bringup phase task and removed bom task from todo
    Added a new item to the TODO list regarding test timelines.

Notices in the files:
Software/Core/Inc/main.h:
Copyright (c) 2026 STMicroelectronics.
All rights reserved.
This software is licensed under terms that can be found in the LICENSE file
